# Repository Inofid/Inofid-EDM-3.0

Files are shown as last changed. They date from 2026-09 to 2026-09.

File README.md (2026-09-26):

# ⚡ EDM-3.0 Компактная и бюджетная версия настольного электроэрозионного станка



[]()

> ### 🚧 Статус разработки (Work in Progress)
>
> Проект находится в стадии активной разработки и тестирования. 
> * **Обратите внимание:** файлы схем (schematics), CAD-моделей и прошивки (Firmware) могут регулярно обновляться.
> * В процессе оптимизации некоторые текущие файлы или проектные решения могут стать неактуальными и быть полностью заменены. Рекомендуется следить за обновлениями.

<table>
  <tr>
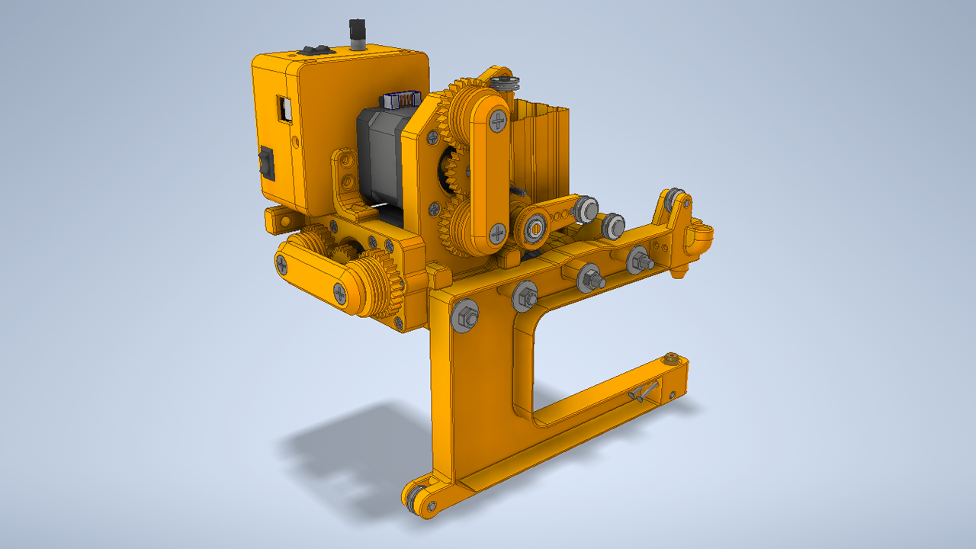
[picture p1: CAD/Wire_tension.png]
Система натяжения проволоки
    <td></td>
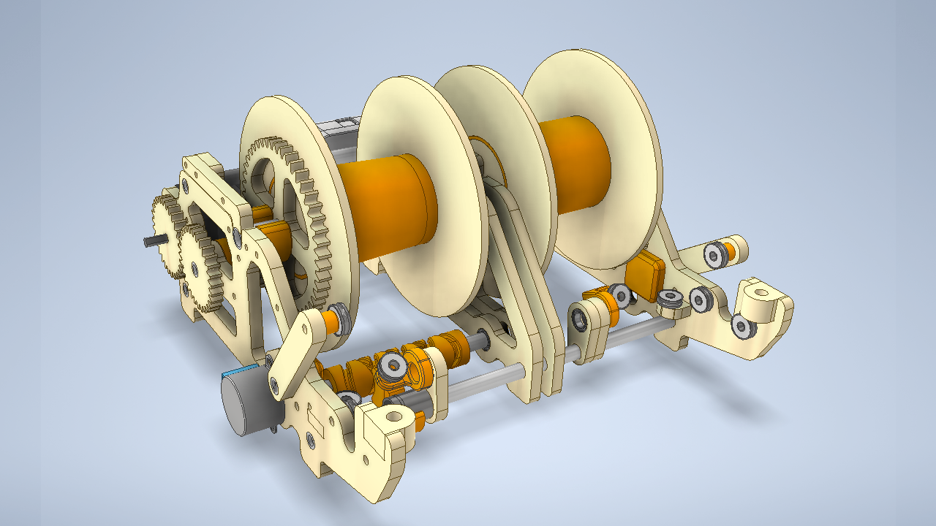
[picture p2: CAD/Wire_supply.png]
Система подачи проволоки
    <td></td>
  </tr>  
</table>

## ⚙ Архитектура и состав проекта (Project Architecture)

Система разработана для быстрой интеграции в простой и доступный ЧПУ станок **CNC3018**. (Изготовление рамы станка не входит в проект)

Для модернизации станка к его рабочему столу крепится ёмкость с водой, а стандартный шпиндель заменяется на модуль натяжения проволоки. На модуле предусмотрен квадратный посадочный выступ 40×40 мм — он вставляется в штатное гнездо бесщеточного шпинделя диаметром 52 мм, вместо самого шпинделя.

### Проект состоит из трех основных независимых систем:

### 1. Система натяжения проволоки
Устанавливается на ось Z станка вместо стандартного шпинделя. Обеспечивает стабильное натяжение проволоки в зоне реза. Проволока поступает в этот модуль из (Системы 2)
* [**3D-модель**](CAD/Wire-tension)
* [**Электрическая схема**](Hardware/Wire_tension)
* [**Прошивка**](Firmware/Wire_Tension)

### 2. Система подачи и отвода проволоки
Располагается рядом со станком. Обеспечивает непрерывную размотку свежей проволоки и смотку отработанной. Проволока поступает в модуль натяжения (Система 1) через гибкие тефлоновые трубки.
* [**3D-модель**](CAD/Wire-supply)
* [**Электрическая схема**](Hardware/Wire_supply)
* [**Прошивка**](Firmware/Wire_supply)

### 3. Генератор импульсов для электроэрозии
Главный электронный блок, который формирует электрические разряды для эрозии металла.
* [**Электрическая схема**](Hardware/Pulse_Generator)
* [**Прошивка**](Firmware/EDM_NEW)

---

## ⚙️ Требования к электронике станка (Electronics Requirements)

Стандартные платы управления CNC3018 обычно оснащены встроенными драйверами шаговых двигателей **A4988**. Однако они **не подходят** для этого проекта.

### Драйверы шаговых двигателей (Stepper Drivers)

Для работы станка необходимо выставлять **микрошаг 1/128 или 1/256**. Стандартные A4988 этого не позволяют.

**Рекомендуемые драйверы:**

- **LV8729** — использовались автором проекта. Микрошаг 1/128 выставляется с помощью перемычек (jumpers).
- **TMC2209** — также подходят, но для микрошага выше 1/64 требуется другой интерфейс подключения (UART), что может быть затруднительно.

### Настройка прошивки (Firmware Settings)

После установки драйверов необходимо изменить следующие параметры в прошивке станка (GRBL):

| Параметр | Значение | Описание |
| :--- | :--- | :--- |
| `$100` / `$101` / `$102` | 6400 | Количество шагов на мм (steps/mm) для осей X/Y/Z |
| `$120` / `$121` | 3000 | Ускорение (acceleration), мм/с² |
| `$110` / `$111` | 100 | Максимальная скорость (max rate), мм/мин |

> - ⚠️ **Количество шагов на мм** зависит от конфигурации конкретного станка. Значение **6400** указано для микрошага 1/128. Пользователь должен перепроверить его самостоятельно.
> - **Ускорение 3000 мм/с²** может показаться высоким, но станок двигается очень медленно, поэтому проблем не возникнет. Такое ускорение необходимо для корректной работы системы поддержания искрового зазора.
> - **Максимальная скорость 100 мм/мин**. Быстрые перемещения с большим микрошагом могут привести к пропуску шагов или зависанию станка, поэтому максимальная скорость ограничена.
>   - Габариты станка небольшие, рабочая область ещё меньше, а холостых перемещений практически не будет: в большинстве случаев стартовое положение выставляется вручную.
>   - Рабочая скорость обычно ещё ниже — до **15 мм/мин**.

---

## 🔌 Требования к электропитанию (Power Requirements)
> [!WARNING]
> **ВЫСОКОЕ НАПРЯЖЕНИЕ!** Система питается от **сети 220 В**. А для работы генератора импульсов используется напряжение **80 В**, которое также представляет опасность. И всё это в непосредственной близости от воды.
> * Будьте предельно осторожны при сборке, отладке и эксплуатации устройства.
> * Автор проекта не несёт ответственности за любой ущерб здоровью или имуществу, полученный в ходе повторения данной конструкции. Все действия вы производите на свой собственный страх и риск.

##

### Для работы всей системы вам понадобятся следующие компоненты:
* **Блок питания 24 В (400 Вт)** — основной источник энергии.
* **Блок питания 12 В (2 А)** — 2 шт. (для раздельного питания логики и периферии).
* **Повышающий DC-DC модуль** — мощный преобразователь, который поднимает напряжение с 24 В до 80 В.

Полная карта межблочных соединений и полярности подключения представлена на схеме ниже:

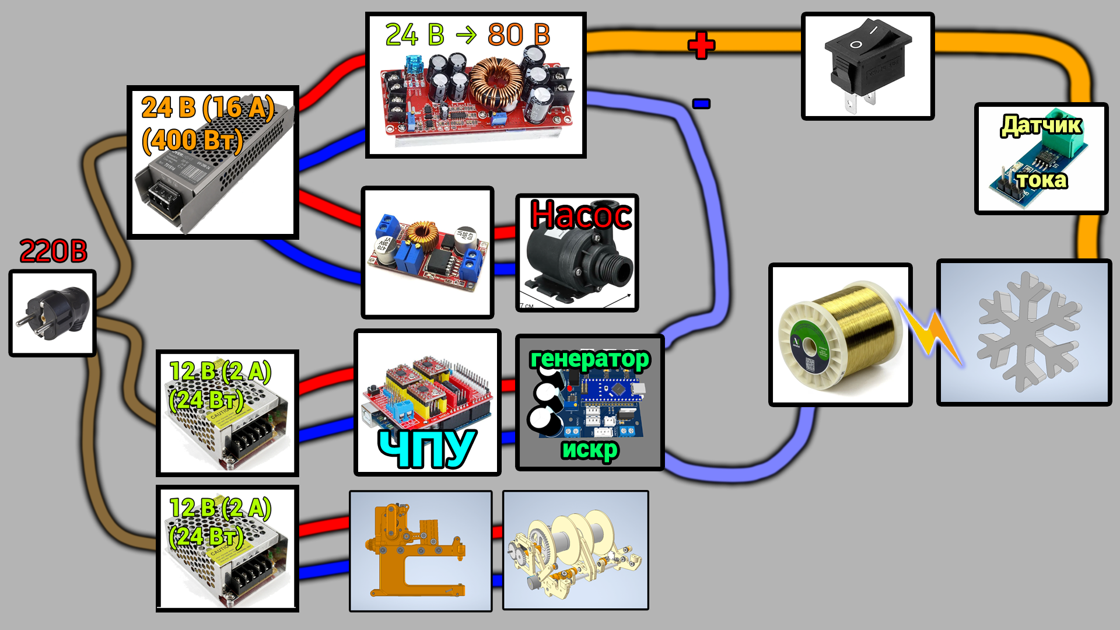
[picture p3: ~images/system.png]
Схема подключения системы


---

## 💧 Система фильтрации и подачи воды (Fluid & Filtration System)

Для эффективного удаления продуктов эрозии (шлама) из зоны реза необходима постоянная циркуляция чистой воды. Система состоит из двух узлов:

* **Магистральный фильтр стандарта SL10 (или большего размера BB10/20)** — используется совместно с многоразовым промываемым картриджем тонкой очистки на **10 мкм**.
* **Центробежный водяной насос** — требуется насос достаточной мощности. Рекомендуется использовать именно **центробежный** насос, так как он выдаёт плавный поток воды без пульсаций. Поршневые или мембранные насосы создают вибрации, которые негативно влияют на стабильность искрового промежутка и точность реза.

---

## 📺 Видео на тему (YouTube):
<table>
  <tr>
    <td align="center"><b>Бюджетный настольный EDM. Часть 1</b></td>
    <td align="center"><b>Бюджетный настольный EDM. Часть 2</b></td>
    <td align="center"><b>Бюджетный настольный EDM. Часть 3</b></td>
  </tr>
  <tr>
    <td>
      <a href="https://youtu.be/et2IkxifwoQ" target="_blank">
        Watch Video 1
      </a>
    </td>
    <td>
      <a href="https://youtu.be/vZhCjU2zuyg" target="_blank">
        Watch Video 2
      </a>
    </td>
    <td>
      <a href="https://youtu.be/VOJPKpydAsk" target="_blank">
        Watch Video 3
      </a>
    </td>
  </tr>
</table>

---

## 📂 Структура репозитория

* [`CAD/`](/CAD) — Исходные файлы (CAD) 3D-моделей для работы в программе Autodesk Inventor.
* [`3D_Models/`](/3D_ModelsD) — STL и STEP файлы для 3D-печати и редактирования в других CAD-программах
* [`Hardware/`](/Hardware) — Исходные файлы электрических схем и плат в EasyEDA
* [`Firmware/`](/Firmware) — Исходный код прошивок (Arduino Code) для микроконтроллеров.
* [`LICENSE`](LICENSE) / [`LICENSE-HARDWARE.md`](LICENSE-HARDWARE.md) — Юридические документы, регламентирующие использование материалов.

---

## ⚖️ Лицензирование (Licensing)

Проект использует двойную схему лицензирования:

* **Программное обеспечение (ПО):** Исходный код прошивки распространяется под лицензией **[MIT License](LICENSE)**.
* **Аппаратное обеспечение (Hardware, CAD):** Все схемы, чертежи, платы и 3D-модели распространяются под лицензией **[Creative Commons Attribution 4.0 International (CC BY 4.0)](LICENSE-HARDWARE.md)**. Вы можете свободно использовать и модифицировать их при условии указания авторства.

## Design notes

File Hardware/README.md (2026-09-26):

# Hardware 🔌🛠

В данном разделе представлены электрические схемы и печатные платы для аппаратных модулей электроэрозионного станка **Inofid-EDM-3.0**.

Все проекты выполнены в среде **EasyEDA**. Внутри каждой директории находятся файлы в формате `.json`, которые можно легко импортировать в EasyEDA (как Standard, так и Pro версии) для просмотра, редактирования или экспорта в Gerber-файлы для заказа плат.

---

## 📁 Структура раздела

Каждый модуль спроектирован на базе микроконтроллера **Arduino Nano** и выполняет свою изолированную задачу в системе станка:

* **Pulse_Generator** — схема генератора высокочастотных импульсов (искрогенератора). Отвечает за управление силовыми мосфетами и обработку обратной связи от датчика тока (компаратора).
  * 💾 **Прошивка:** [EDM_NEW](https://github.com/Inofid/Inofid-EDM-3.0/tree/main/Firmware/EDM_NEW)
* **Wire_supply** — схема системы автоматической подачи свежей и отвода отработанной проволоки. Управляет шаговыми двигателями катушек на основе положения рычагов.
  * 💾 **Прошивка:** [Wire_supply](https://github.com/Inofid/Inofid-EDM-3.0/tree/main/Firmware/Wire_supply)
* **Wire_tension** — схема системы контроля натяжения проволоки. Динамически подстраивает скорость шагового двигателя через PID-алгоритм для поддержания стабильного натяжения.
  * 💾 **Прошивка:** [Wire_Tension](https://github.com/Inofid/Inofid-EDM-3.0/tree/main/Firmware/Wire_Tension)

---

## 🖼 Галерея проектов

| Название проекта | Pulse_Generator | Wire_supply | Wire_tension |
| :--- | :---: | :---: | :---: |
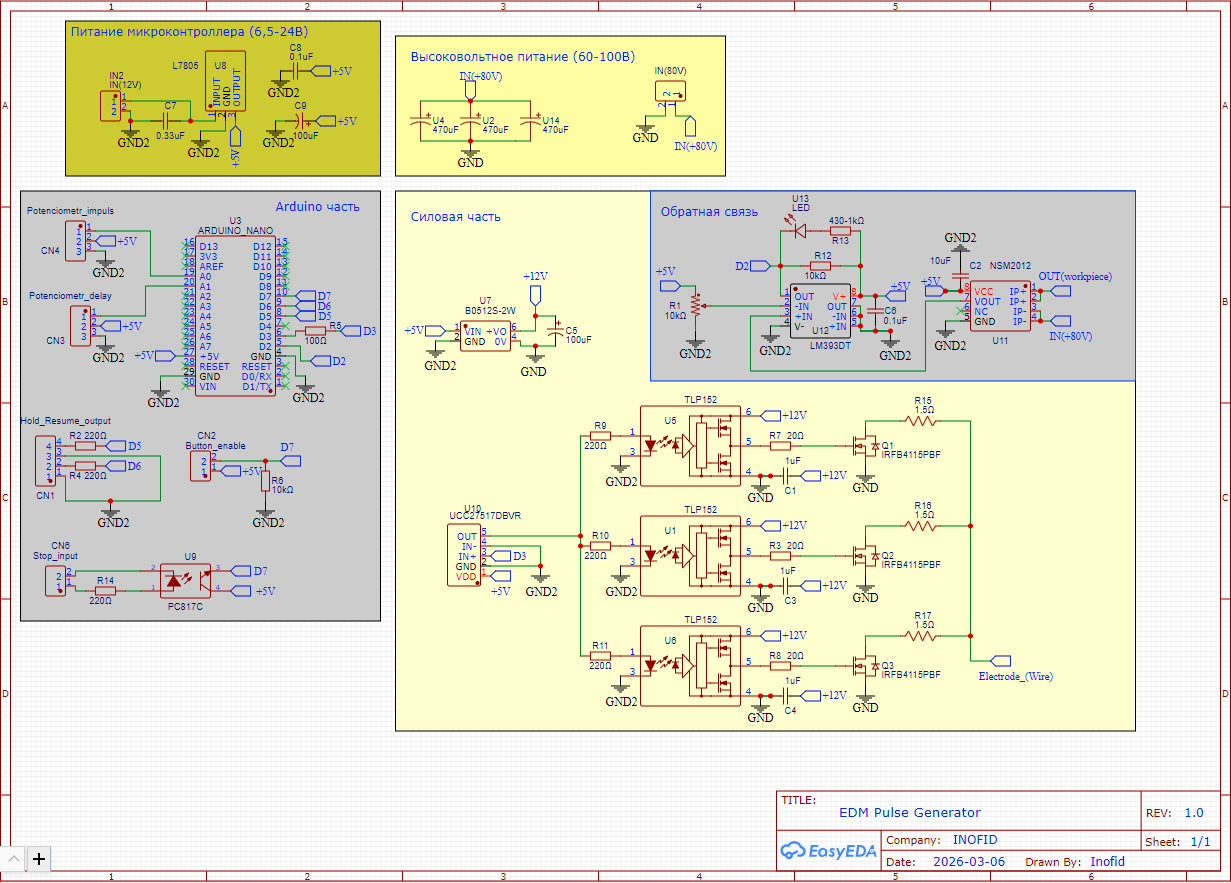
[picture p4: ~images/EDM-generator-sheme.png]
Схема Pulse_Generator
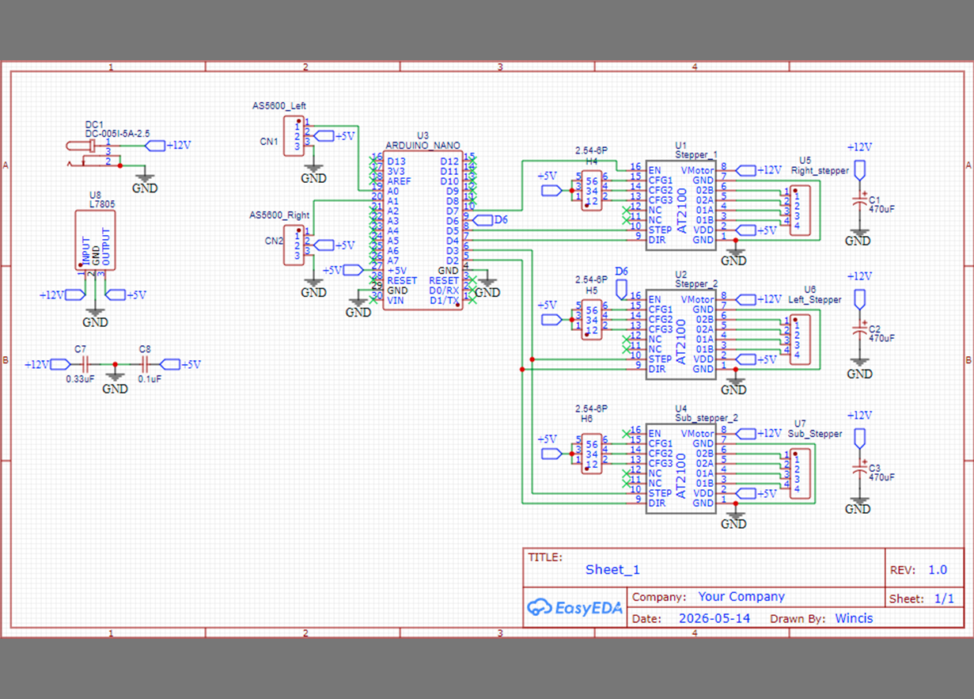
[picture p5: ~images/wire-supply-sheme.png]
Схема Wire_supply
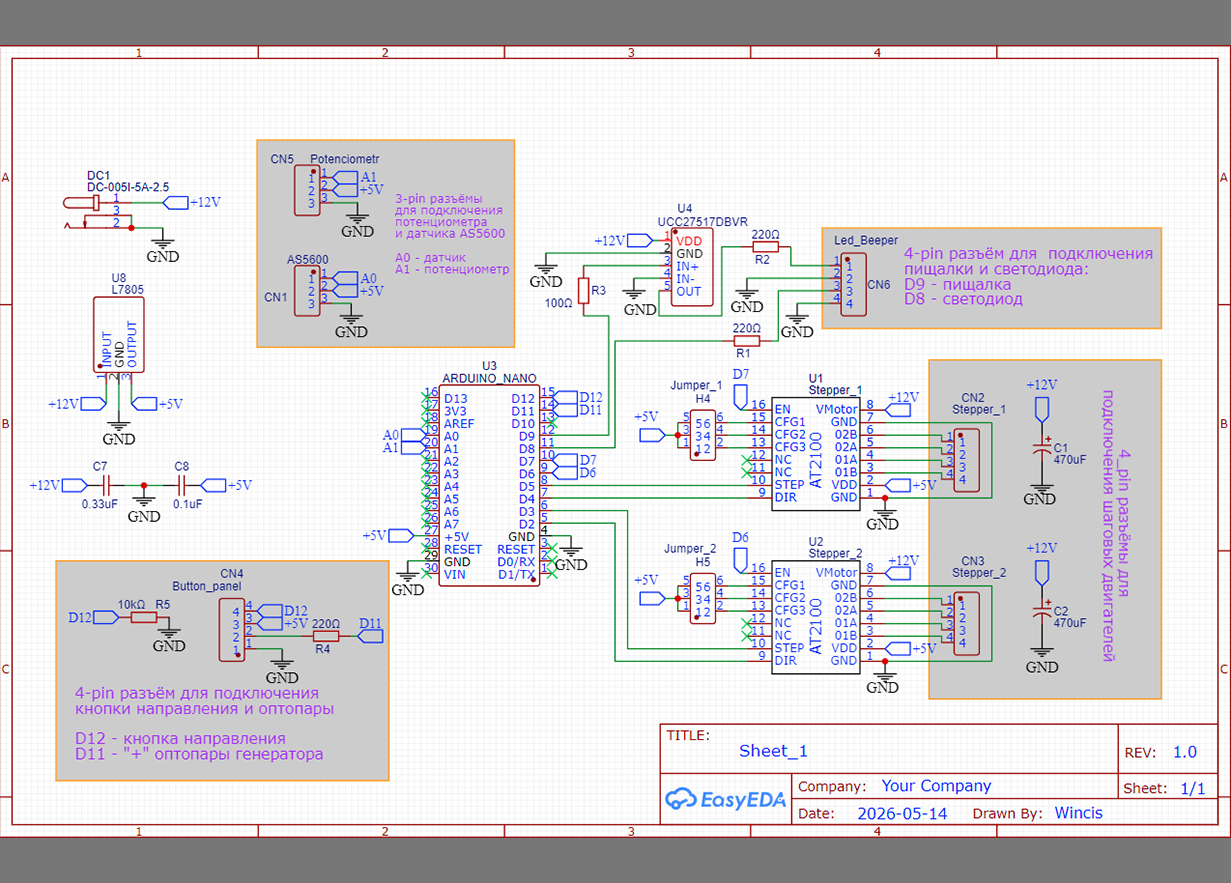
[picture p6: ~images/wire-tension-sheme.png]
Схема Wire_tension
| **Электрическая схема** |  |  |  |
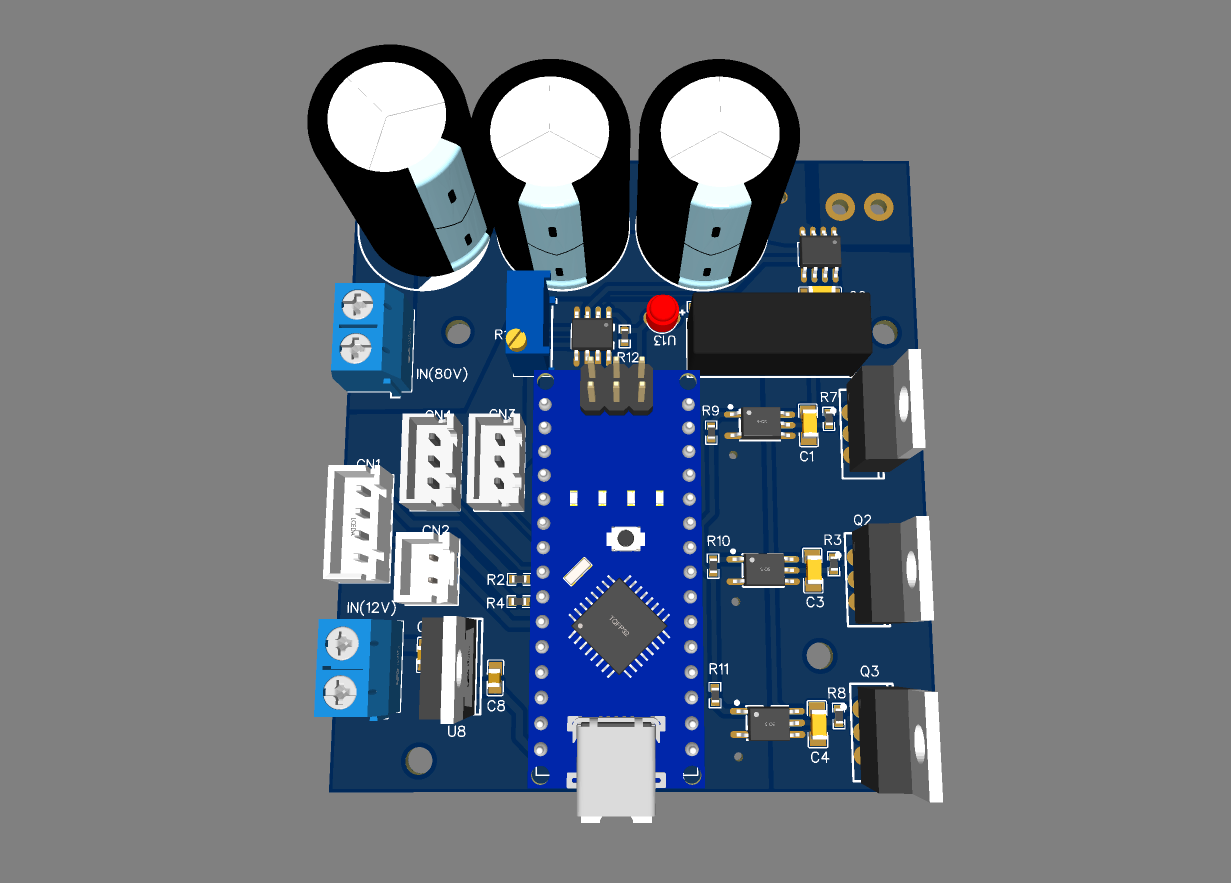
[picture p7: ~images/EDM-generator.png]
Плата Pulse_Generator
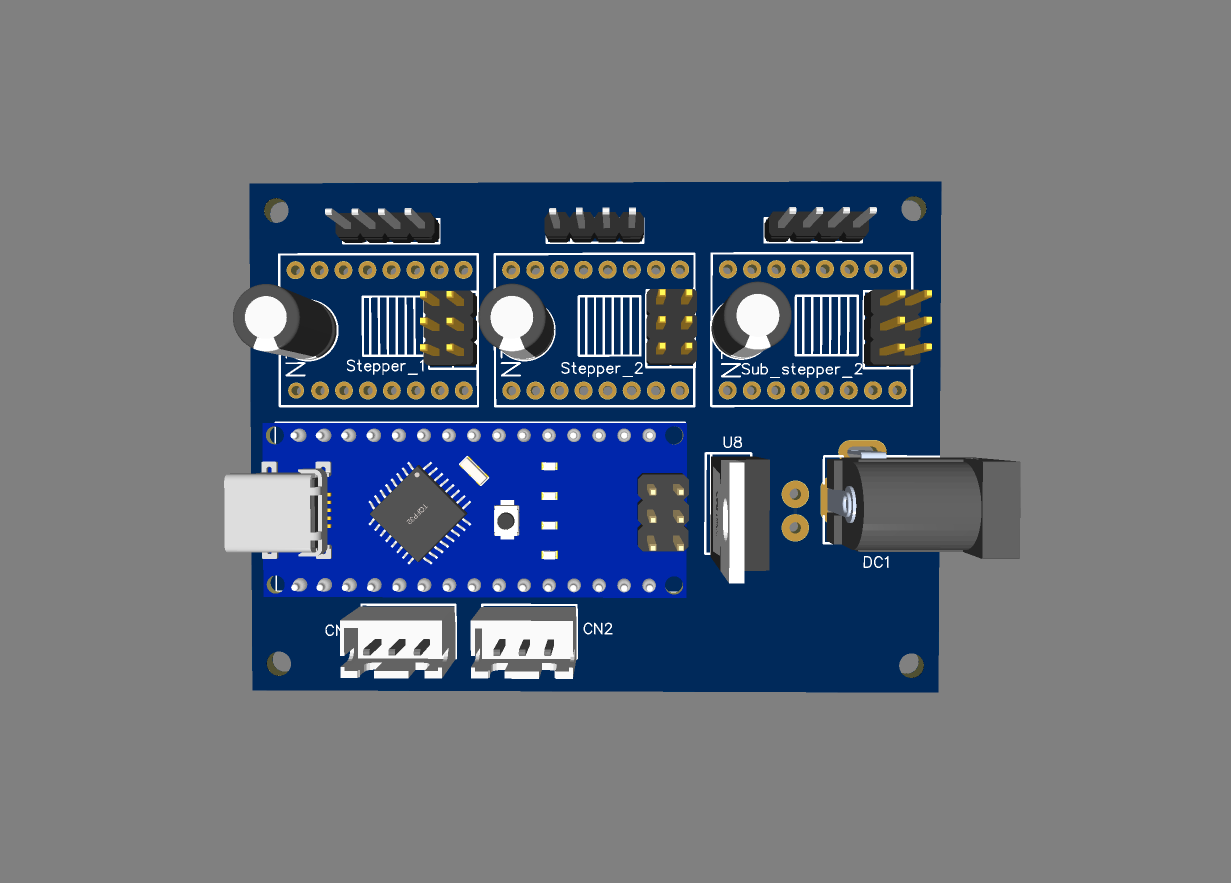
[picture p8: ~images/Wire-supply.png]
Плата Wire_supply
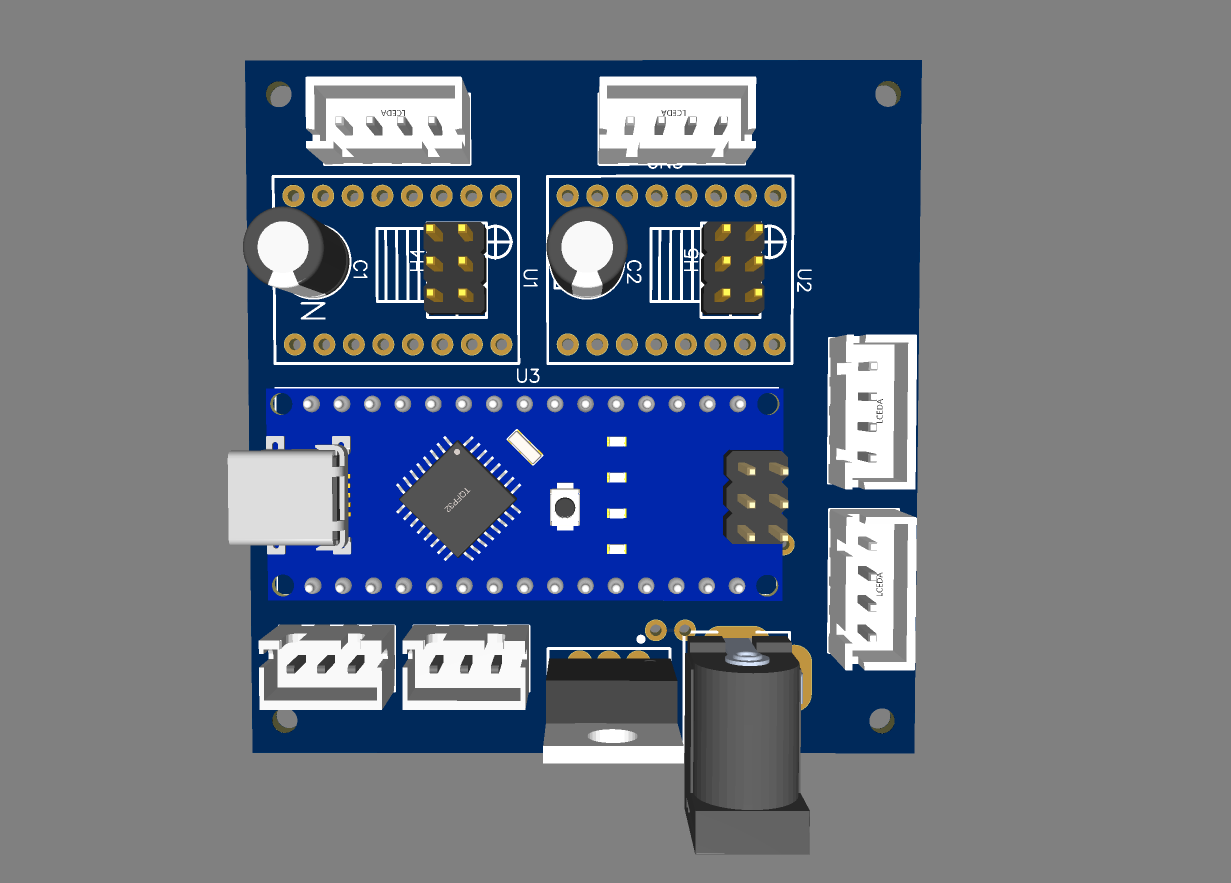
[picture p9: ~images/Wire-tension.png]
Плата Wire_tension
| **Внешний вид платы** |  |  |  |

---

## 🚀 Как открыть файлы в EasyEDA

1. Откройте онлайн-редактор [EasyEDA](https://easyeda.com/editor) или запустите десктопное приложение.
2. В верхнем левом меню выберите: **Файл (File)** ➡️ **Открыть (Open)** ➡️ **EasyEDA...**
3. Загрузите соответствующий `.json` файл из папки интересующего вас модуля.

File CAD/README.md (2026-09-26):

# 3D-модели Autodesk Inventor

В этой папке содержатся исходные файлы 3D-моделей, сборочных узлов и отдельных деталей, созданных в **Autodesk Inventor**.

### Предварительный просмотр 3D-моделей
<table>
  <tr>
    <td align="center"><b>Система натяжения проволоки</b></td>
    <td align="center"><b>Система подачи проволоки</b></td>
  </tr>
  <tr>
    <td>Система натяжения проволоки</td>
    <td>Система подачи проволоки</td>
  </tr>
</table>

### Расположение файлов:
*  В папке "Wire-tension" — главный файл сборки **"Модуль.iam"**
*  В папке "Wire-supply" — главный файл сборки **"Система подачи и забора проволоки.iam"**

### Информация об изготовлении деталей:
* **Проект в папке "Wire-tension"** — полностью рассчитан на печать всех деталей на 3D-принтере. Рамка выполнена в виде формы для заливки бетоном/полимербетоном.
* **Проект в папке "Wire-supply"** — содержит детали двух типов:
  * 🟠 **Оранжевые детали** — печатаются на 3D-принтере.
  * 🟡 **Бежевые детали** — вырезаются на лазерном станке из фанеры толщиной 6 мм. Фанерные детали соединены алюминиевыми трубками 8 мм.

### Типы файлов в этой папке:
* `.iam` — файлы сборок 
* `.ipt` — файлы отдельных деталей

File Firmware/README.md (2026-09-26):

# Прошивка и исходный код

В этой папке находится исходный код (скетчи Arduino) для подсистем управления электроэрозионного (EDM) станка. Прошивка разделена на модули для трех отдельных микроконтроллеров.

## Обзор подсистем

*   📂 **[EDM_NEW](./EDM_NEW)** — Прошивка генератора импульсов. Отвечает за управление высокочастотными электрическими разрядами и контроль искрового промежутка.
*   📂 **[Wire_Tension](./Wire_Tension)** — Система управления натяжением проволоки. Управляет контуром обратной связи для поддержания оптимального натяжения проволоки во время работы.
*   📂 **[Wire_supply](./Wire_supply)** — Система подачи и приемки проволоки. Контролирует непрерывную подачу свежей, и отвод отработанной проволоки.

---

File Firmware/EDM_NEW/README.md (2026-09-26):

# Генератор импульсов (искрогенератор) (Arduino Nano)

Данный скетч предназначен для управления мосфетами, генерирующими высокочастотные импульсы, и автоматического регулирования подачи станка на основе обратной связи от датчика тока (компаратора).

> [!WARNING]
> ⚠️ **ВНИМАНИЕ! ВЫСОКОЕ НАПРЯЖЕНИЕ!** Для работы генератора импульсов используется опасное для жизни напряжение **80 В**. 
> * Будьте предельно осторожны при сборке, отладке и эксплуатации устройства. Особенно с учётом наличия рядом ёмкости с водой.
> * Автор проекта не несёт ответственности за любой ущерб здоровью или имуществу, полученный в ходе повторения данной конструкции. Все действия вы производите на свой собственный страх и риск.

## 📌 Распиновка и схема подключений

### 1. Входы (Inputs)
*   **A0** — Потенциометр длительности импульса (регулировка диапазона **2–25 мкс**).
*   **A1** — Потенциометр паузы между импульсами (регулировка частоты **1–20 кГц**, диапазон паузы **40–1000 мкс**).
*   **D7** — Переключатель режимов (Настройка / Работа).
    >⚠️ Пин должен быть обязательно **подтянут к GND через резистор 10 кОм**. При замыкании переключателя, на D7 подается **+5V** с платы Arduino.
*   **D4** — Вход сигнала с компаратора датчика тока.
    >⚠️ Опрос этого пина в коде происходит строго **в конце импульса**, непосредственно перед закрытием мосфета. Это критично для обратной связи, так как ток в цепи может отсутствовать в начале импульса, но может появиться ближе к его завершению. Это позволяет более корректно оценивать был ли импульс холостым или полезным.

### 2. Выходы (Outputs)
*   **D3** — Выход сигнала управления драйвером силовых MOSFET-ключей.
*   **D5** — Выход на оптопару **RESUME** (Продолжение движения).
*   **D6** — Выход на оптопару **PAUSE / HOLD** (Станок на паузу).

---

## 🔌 Подключение оптопар и интеграция со станком

Светодиодная (входная) часть обеих оптопар подключается к Arduino по классической схеме:
*   **Анод (+)** оптопары — к соответствующему пину Arduino (**D5** или **D6**) через токоограничивающий **резистор 220 Ом**.
*   **Катод (-)** оптопары — напрямую на **GND** платы Arduino.

Так как оптопары (PC 817) не являются частью родной платы управления станком, а подключаются отдельно, их выходная (транзисторная) часть подключается к пинам `Hold` и `Resume` контроллера станка следующим образом:
*   **Эмиттер** транзистора оптопары — соединяется с **GND** платы управления станком.
*   **Коллектор** транзистора оптопары — подключается к сигнальному входу пина **Hold** (для оптопары с D6) или пина **Resume** (для оптопары с D5).

---

## ⚙️ Логика работы

1.  **Режим настройки (На D7 подано +5V):**
    *   Генерация импульсов полностью останавливается (мосфет закрыт).
    *   Включается оптопара PAUSE на пине D6 (станок замораживает движение).
    *   В реальном времени считываются показания с потенциометров A0 и A1 для калибровки таймингов.
2.  **Режим работы (На D7 подан GND через 10 кОм):**
    *   Запускается циклическая генерация импульсов заданной длительности на пине D3.
    *   В конце каждого импульса опрашивается состояние пина D4. Если зафиксирован ток, инкрементируется внутренний счетчик `q`, если тока нет — декрементируется.
    *   **Автоматика:** При избытке полезных импульсов (`q >= 950`) активируется пин D6 (Hold), приостанавливая подачу станка. При нехватке импульсов (`q <= 850`) активируется пин D5 (Resume), возобновляя движение.
> ###  ⚠️ **Примечание:** 
> Опрос потенциометров происходит только в режиме настройки (когда на D7 подано 5В). Поэтому не получится изменять частоту и длительность импульсов в режиме реального времени во время работы станка. Такая реализация нужна > из-за медлительности микроконтроллера Atmega328. Опрос потенциометров занимает слишком много времени, что нарушает стабильность генерации импульсов.
***

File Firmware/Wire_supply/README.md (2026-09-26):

# Wire_supply 🧵🎛️

Прошивка для **Arduino Nano**, управляющая системой автоматической подачи свежей и отвода отработанной проволоки для **электроэрозионного станка (EDM)**.

---

## 📋 Описание системы

Система состоит из двух идентичных модулей:
* **Модуль подачи** свежей проволоки
* **Модуль отвода** отработанной проволоки

Каждый модуль оснащен катушкой и подпружиненным рычагом контроля натяжения. Шаговые двигатели вращают катушки, а скорость их вращения динамически рассчитывается с помощью **PID-регулятора** (`GyverPID`) на основе угла наклона рычагов. Это позволяет непрерывно поддерживать оптимальное натяжение проволоки.

### 🛑 Логика «мёртвой» зоны и обрыва:
* **Автоостановка**: При запуске станка, а также в случае обрыва проволоки, пружины уводят рычаги в крайнее положение. Если показания датчика выходят за рабочий диапазон (становятся **меньше 50** или **больше 600**), прошивка расценивает это как «мёртвую» зону и останавливает шаговые двигатели.
* **Быстрый старт**: Чтобы запустить систему, достаточно вручную натянуть проволоку или отклонить рычаг, выведя датчик из мёртвой зоны. Двигатели запустятся автоматически.

---

## 🔌 Подключение компонентов

| Компонент | Пин Arduino Nano | Описание |
| :--- | :---: | :--- |
| **Шаговый двигатель 1 (Драйвер TMC2209)** | `D3` (STEP), `D2` (DIR) | Вращение катушки 1 [4] |
| **Шаговый двигатель 2 (Драйвер TMC2209)** | `D5` (STEP), `D4` (DIR) | Вращение катушки 2 [4] |
| **Датчик AS5600 №1 (в аналоговом режиме)** | `A0` (OUT) | Положение рычага 1 [4] |
| **Датчик AS5600 №2 (в аналоговом режиме)** | `A1` (OUT) | Положение рычага 2 [4] |

---

## 🛠️ Настройка и калибровка датчиков AS5600

В проекте используются магнитные энкодеры **AS5600**, переведённые в аналоговый режим работы.

### 1. Перевод в аналоговый режим
Чтобы датчик выдавал непрерывное аналоговое напряжение вместо I2C/PWM сигналов, на плате модуля необходимо **отпаять резистор R4**. 
После чего датчик будет работать в аналоговом режиме и на пине **"`OUT`"** будет выдавать напряжение от 0 В до 5 В, в зависимости от положения рычага.

Размещение резистора указано на изображении ниже:

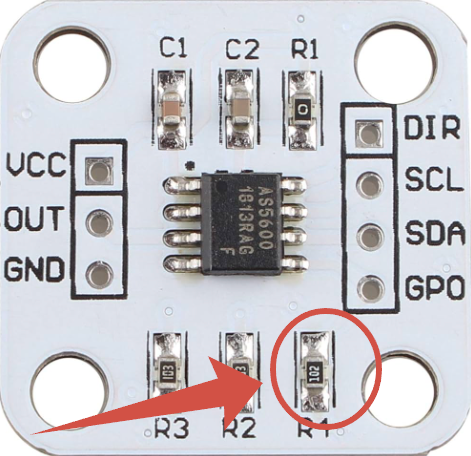
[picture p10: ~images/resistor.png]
Расположение резистора R4


### 2. Зеркальное изменение направления (DIR)
Так как модули на станке расположены зеркально друг относительно друга, направления движения рычагов противоположны. Для корректной работы PID-алгоритма нужно настроить пин `DIR` на самих датчиках:
* **На первом датчике**: Замкните пин `DIR` на **GND**.
* **На втором датчике**: Замкните пин `DIR` на **VCC**.

> **Проверка**: При наклоне обоих рычагов из начального положения в рабочее, значения на аналоговых входах должны **увеличиваться**.

### 3. Калибровка положения магнитов
Перед запуском необходимо физически отъюстировать магниты на осях рычагов. В **свободном (начальном)** положении подпружиненного рычага датчик должен выдавать значения `analogRead()` в диапазоне **от 10 до 15**.

Залейте в Arduino этот простой калибровочный скетч и вращайте магнит, пока не добьетесь значений в мониторе порта (от 10 до 15):

```cpp
void setup() {
  Serial.begin(9600);
}

void loop() {
  // Считываем значения с пинов A0 и A1
  int sensor1 = analogRead(A0);
  int sensor2 = analogRead(A1);

  // Выводим данные в монитор порта
  Serial.print("Рычаг 1 (A0): ");
  Serial.print(sensor1);
  Serial.print("\t | \tРычаг 2 (A1): ");
  Serial.println(sensor2);

  delay(150); // Задержка для удобства чтения
}
```

---

## 📚 Зависимости
Для сборки основного проекта `Wire_supply` необходимы библиотеки:
* [TimerOne](https://github.com) — для генерации стабильных прерываний таймера.
* [GyverPID](https://github.com) — для работы PID-регуляторов.

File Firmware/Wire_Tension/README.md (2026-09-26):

# Wire Tension Controller (Arduino Nano)

Данный проект представляет собой систему автоматического контроля натяжения проволоки на базе микроконтроллера **Arduino Nano**. Устройство управляет двумя шаговыми двигателями: скорость первого динамически подстраивается через PID-регулятор для поддержания натяжения, а скорость второго задается вручную пользователем.

---

## ⚙️ Основные функции
* **Автоматическое поддержание натяжения:** Отслеживание положения рычага с помощью магнитного энкодера AS5600 и корректировка скорости ШД через PID-алгоритм.
* **Ручное управление вторым ШД:** Регулировка скорости потенциометром и смена направления вращения с помощью кнопки.
* **Безопасность и мониторинг:** 
  * Определение обрыва проволоки или выхода рычага за рабочие пределы с автоматической остановкой моторов и звуковым оповещением.
  * Контроль проскальзывания проволоки при сильном расхождении скоростей двигателей.
---

## 🔌 Схема подключения (Пинкаут)

### 1. Шаговые двигатели & Драйверы (TMC2209)

| Назначение | Пин Arduino | Описание |
|---|---|---|
| **STEP 1** | `D3` | Пин Step драйвера 1-го ШД |
| **DIR 1** | `D2` | Пин Dir драйвера 1-го ШД  |
| **ENABLE 1** | `D6` | Пин Enable драйвера 1-го ШД |
| **STEP 2** | `D5` | Пин Step драйвера 2-го ШД |
| **DIR 2** | `D4` | Пин Dir драйвера 2-го ШД  |
| **ENABLE 2** | `D7` | Пин Enable драйвера 2-го ШД  |

### 2. Датчики и Органы управления

| Компонент | Пин Arduino | Описание |
|---|---|---|
| **AS5600 (Out)** | `A0` | Аналоговый выход датчика положения рычага  |
| **Потенциометр** | `A1` | Регулятор скорости 2-го ШД (шаги/сек)  |
| **Кнопка направления** | `D12` | Переключатель направления 2-го ШД. При нажатии — подает `5V`, при отпускании — подтянут к `GND` через резистор **10 кОм**  |

### 3. Индикация и Оповещение

| Компонент | Пин Arduino | Описание |
|---|---|---|
| **Сигнальный LED** | `D8` | Светодиод аварии/проскальзывания (подключать через резистор **220 Ом**)  |
| **Пищалка (Buzzer)** | `D9` | Выход на специализированный драйвер **UCC27517DBVR** (для обеспечения достаточного тока и громкого звука пищалки. Напрямую от пина Arduino питать пищалку нельзя). |

---

## 🛠 Настройка датчика AS5600

### 1. Перевод модуля AS5600 в аналоговый режим
По умолчанию большинство плат датчика AS5600 настроены на работу по шине I2C или выдают ШИМ (PWM). Чтобы перевести датчик в **режим вывода аналогового напряжения (Analog Out)** на пине **"`OUT`"**:
* На стандартных китайских платах AS5600 необходимо **отпаять резистор R4**, подтягивающий пин выбора режима. Это переводит выходной каскад микросхемы в режим `Analog Ratiometric`, выдающий от 0 до 5V пропорционально углу поворота.

Resistor AS5600

### 2. Калибровка магнита и рычага
Для корректной работы PID-регулятора в начальном положении рычага значение `analogRead(A0)` должно находиться строго в диапазоне **от 0 до 15**. 

Используйте этот короткий тестовый скетч для точной юстировки магнита:

```cpp
void setup() {
  Serial.begin(9600);
  pinMode(A0, INPUT);
}

void loop() {
  int rawValue = analogRead(A0);
  Serial.print("Положение магнита (Analog A0): ");
  Serial.println(rawValue);
  delay(200); // Задержка для читаемости в мониторе порта
}
```

**Инструкция по настройке:**
1. Залейте тестовый скетч в Arduino Nano.
2. Переведите рычаг устройства в **исходное (начальное) положение**.
3. Вращайте и смещайте постоянный магнит на оси рычага относительно микросхемы AS5600, пока в Мониторе порта значения `analogRead` не стабилизируются в диапазоне **0...15**.
4. Надежно зафиксируйте магнит в этом положении.
 #### ⚠️Обратите внимание, что при наклоне рычага в рабочем направлении, значение должно увеличиваться, а не уменьшаться. Если это не так, то пин DIR на модуле AS5600 необходимо замкнуть либо на GND, либо на VCC.
---

## 🔍 Алгоритм обнаружения проскальзывания

Система безопасности непрерывно контролирует разницу скоростей между двумя двигателями во избежание проскальзывания проволоки:
1. Скорость 2-го двигателя (`spd2`) задается жестко потенциометром.
2. Скорость 1-го двигателя (`spd1`) динамически рассчитывается PID-регулятором.
3. Каждые 40 итераций основного цикла происходит сверка скоростей (проверка завязана на программный счетчик `i` из-за перегрузки таймера прерываниями, управляющими ШД).
4. Если модуль разницы скоростей превышает **200 шагов/сек** (`abs(spd2 - abs(spd1)) > 200`), устройство считает, что проволока проскальзывает, и генерирует короткий звуковой/световой сигнал.

---

## 🚀 Инструкция по эксплуатации

### Старт работы и сброс аварии
1. При включении устройства рычаг находится в начальном положении (`analogRead(A0) < 15`).
2. Система сразу переходит в режим аварии: моторы отключены, а пищалка издает двухтональный протяженный сигнал тревоги.
3. **Для запуска работы:** необходимо **вручную наклонить рычаг** натяжителя так, чтобы датчик попал в рабочую зону (значение `analogRead(A0)` станет больше 15).
4. Как только рычаг зафиксирован в рабочей зоне, двигатели автоматически активируются, и PID-регулятор начинает удерживать заданное натяжение.

---

## 📁 Структура проекта

Проект логически разделен на модули (вкладки в Arduino IDE) для удобства чтения:
* **`Wire_Tension.ino`** — главный файл. Инициализирует периферию, содержит основной цикл `loop()` с логикой аварии, расчетом PID и маппингом потенциометра.
* **`alarm.ino`** — функции оповещения: `alarm()` для обработки обрыва/старта и `alarm_slippage()` для индикации проскальзывания.
* **`pid.ino`** — инициализация и конфигурирование базовых параметров PID-регулятора (`Kp`, `Ki`, `Kd`, направление регулирования и лимиты скоростей).
* **`timers.ino`** — обработчик прерывания таймера `timerISR()` для пошаговой генерации импульсов ШД, а также функции установки скоростей `setSpeed1()` и `setSpeed2()` с прямым управлением регистрами портов (`PORTD`) для максимального быстродействия.

## 📚 Зависимости
Для компиляции скетча требуются библиотеки:
* **TimerOne** (генерация точных интервалов шагов в прерывании)
* **GyverPID** (библиотека PID-регулятора от AlexGyver)

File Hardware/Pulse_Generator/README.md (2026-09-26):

# ⚡ Генератор импульсов для электроэрозионного станка (Pulse Generator)

<table>
  <tr>
    <td align="center"><b>Схема генератора импульсов</b></td>
    <td align="center"><b>Готовая плата генератора</b></td>
  </tr>
  <tr>
    <td>Принципиальная схема генератора импульсов</td>
    <td>Фото готовой печатной платы генератора</td>
  </tr>
</table>

> [!WARNING]
> ⚠️ **ВНИМАНИЕ! ВЫСОКОЕ НАПРЯЖЕНИЕ!** Для работы генератора импульсов используется опасное для жизни напряжение **80 В**.
> * Будьте предельно осторожны при сборке, отладке и эксплуатации устройства. Особенно с учётом наличия рядом ёмкости с водой.
> * Автор проекта не несёт ответственности за любой ущерб здоровью или имуществу, полученный в ходе повторения данной конструкции. Все действия вы производите на свой собственный страх и риск.

---

## 📖 Описание

Электронная схема генератора импульсов для электроэрозионного станка на базе **Arduino Nano**.

Устройство генерирует прямоугольные импульсы с настраиваемой длительностью и частотой, а также определяет факт возникновения искры (электрического разряда) во время импульса.

* **Логика работы** более подробно описана в папке с [прошивкой](../../Firmware/EDM_NEW)

---

## ⚙️ Состав устройства

Схема состоит из **5-ти основных блоков**:

### 1. Питание микроконтроллера (12–24 В)

- **Разъём питания** для подачи входного напряжения.
- **Стабилизатор L7805** понижает входное напряжение до **5 В**.
  - Керамический конденсатор **0,33 мкФ** на входе и **0,1 мкФ** на выходе — требование даташита.
  - Электролитический конденсатор **100 мкФ** — для дополнительной стабилизации.

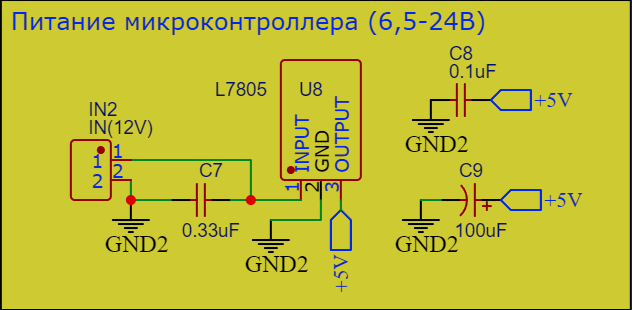
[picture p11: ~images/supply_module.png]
supply_module


### 2. Блок Arduino Nano

- **Разъём (U3)** для установки платы Arduino Nano.
- **Разъёмы** для подключения потенциометров, регулирующих длительность импульсов (CN4) и частоту (CN3).
- **Разъём (CN1)** для подключения внешних оптопар, управляющих пинами **HOLD/RESUME** на плате управления станком.
- **Разъём (CN2)** для подключения кнопки (подаёт 5 В на пин **D7**).
- **Разъём (CN6)** для управления оптопарой. Эта оптопара дублирует кнопку выше, то есть также подаёт 5 В на пин **D7**. Оптопара активируется модулем натяжения проволоки в случае обрыва проволоки, таким образом станок переходит в режим паузы.

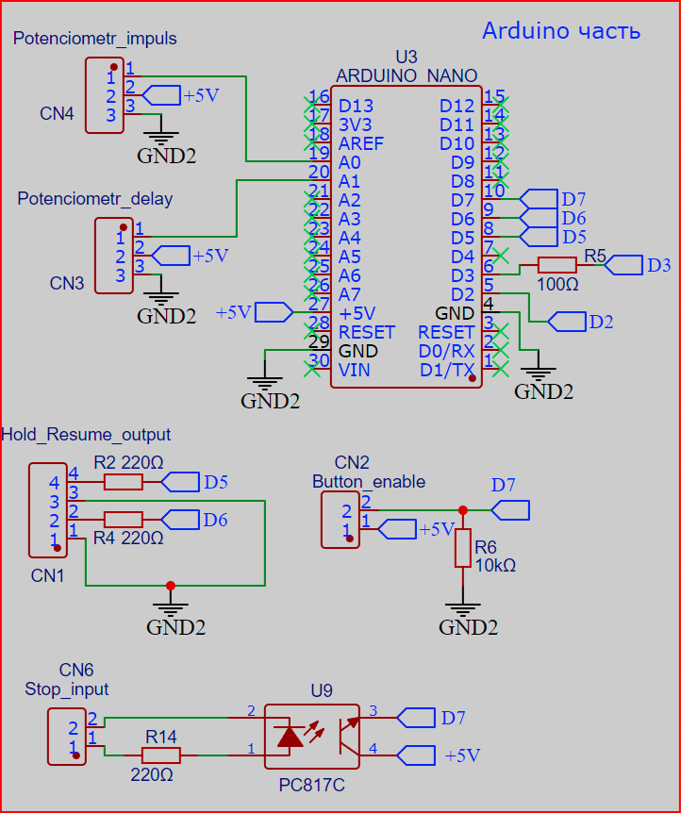
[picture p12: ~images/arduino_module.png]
arduino_module


### 3. Высоковольтное питание

- **Разъём** для подключения напряжения от **60 до 100 В**.
- **Блок конденсаторов** с низким ESR (470 мкФ).

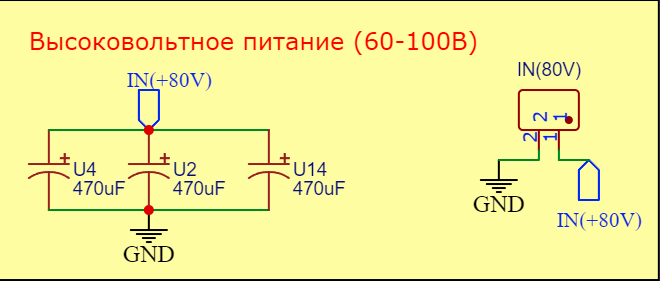
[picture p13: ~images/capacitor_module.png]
capacitor_module


### 4. Силовая часть

- **Элемент B0512S-2W** — модуль гальванической развязки повышает **5 В до 12 В**, необходимых для управления затворами мосфетов.
  - На выходе электролитический конденсатор на **100 мкФ** для стабилизации питания.
- **Сигнал** от пина **D3** Arduino поступает на драйвер **UCC27517DBVR**. Драйвер через резисторы **220 Ом** управляет тремя оптодрайверами **TLP152**. Каждый оптодрайвер через резистор **20 Ом** управляет соответствующим мосфетом **IRFB4115PBF**. Питание **12 В** для управления затворами поступает от модуля гальванической развязки **B0512S-2W**.
  - Параллельно и как можно ближе к контактам питания элементов **TLP152** стоят керамические конденсаторы на **1 мкФ**.
- **На выходе каждого мосфета** стоит нагрузочный резистор **1,5 Ом** мощностью **100 Вт** (тип **AH-100**). Он нужен для защиты мосфета в случаях короткого замыкания.
  - **Важно:** эти резисторы выносятся за пределы печатной платы и монтируются на радиаторы, так как выделяют значительное количество тепла.
- **Параллельно каждому мосфету** стоит защитный диод **1.5KE120A**. Их задача — защищать мосфеты от индукционных выбросов.
- **На выходе** резисторы соединяются вместе, и ток дальше подаётся через токосъёмники на проволоку.
- **Мосфеты** крайне желательно снабдить радиаторами. Также и резисторы желательно прикрутить к радиаторам либо организовать активное охлаждение.

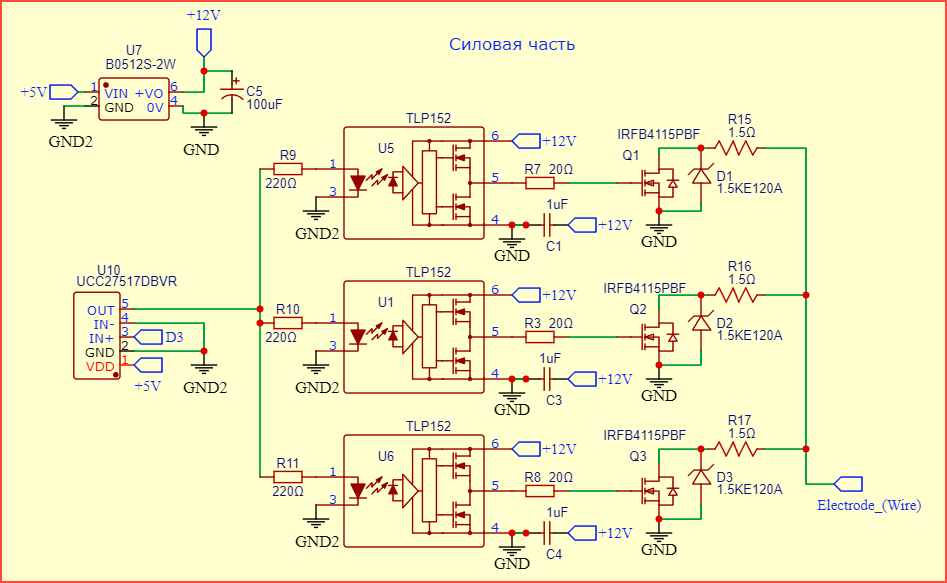
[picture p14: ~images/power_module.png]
power_module


### 5. Обратная связь

- **Плюсовая линия питания 80 В** проходит через датчик тока **NSM2012**
  > (датчик тока размещён после конденсаторов, он должен мгновенно реагировать на каждый импульс).
- **Сигнальный выход** этого датчика поступает на вход компаратора **LM393DT**.
- **Порог срабатывания** компаратора устанавливается вручную с помощью подстроечного резистора.
- **Момент срабатывания** можно увидеть благодаря светодиоду.

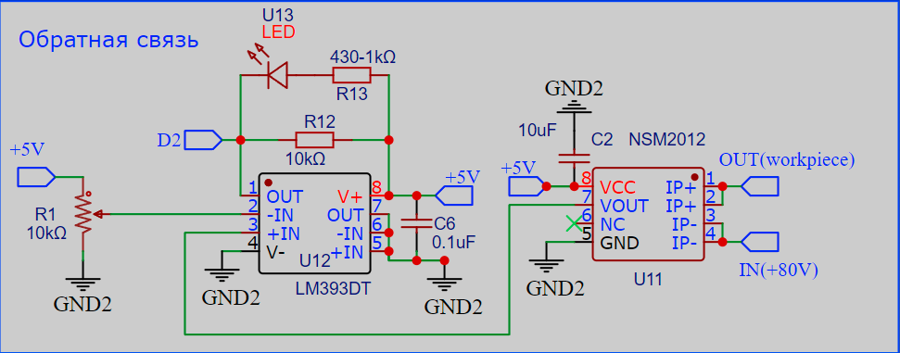
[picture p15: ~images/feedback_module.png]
feedback_module


**Настройка порога срабатывания компаратора:**

1. Выставить минимальную длительность импульсов и частоту.
2. Замкнуть проволоку и заготовку, чтобы было короткое замыкание.
3. Запустить генерацию импульсов (генератор спокойно выдержит короткое замыкание).
4. Подкрутить подстроечный резистор, пока не загорится светодиод.
5. Отвести проволоку от заготовки, чтобы разомкнуть цепь, и убедиться, что светодиод погас.
6. Желательно перепроверить несколько раз, что компаратор правильно срабатывает на замыкание/размыкание цепи.

---

## 📝 Примечания

> Потенциометр, регулирующий частоту импульсов, на самом деле регулирует длительность паузы между импульсами. Это косвенно связано с частотой, но при повороте потенциометра по часовой стрелке длительность паузы будет увеличиваться, а частота соответственно уменьшаться. Это не совсем привычно. Если это сбивает с толку, то на потенциометре можно просто поменять местами пины питания. Тогда при повороте потенциометра вправо будет увеличиваться частота импульсов (а длительность паузы соответственно уменьшаться).

> **О проводах:** Провода, идущие к заготовке и проволоке, должны быть потолще и скручены в витую пару для снижения их индуктивности и защиты окружающей электроники от электромагнитных помех.

---

## 📋 Список компонентов

| № | Компонент | Номинал / Модель | Кол-во | Примечание |
|---|---|---|:---:|---|
| 1 | Стабилизатор напряжения | L7805 | 1 | Понижает входное напряжение до 5 В |
| 2 | Плата Arduino | Arduino Nano | 1 | Микроконтроллер |
| 3 | Модуль гальванической развязки | B0512S-2W | 1 | 5 В → 12 В |
| 4 | Драйвер MOSFET | UCC27517DBVR | 1 | Управление оптодрайверами |
| 5 | Оптодрайвер | TLP152 | 3 | Управление мосфетами |
| 6 | Оптопара | PC817C | 1 | Гальваническая развязка сигнала D7 |
| 7 | MOSFET | IRFB4115PBF | 3 | Силовые ключи |
| 8 | Датчик тока | NSM2012 | 1 | Измерение тока |
| 9 | Компаратор | LM393DT | 1 | Сравнение сигнала |
| 10 | Светодиод | LED (красный) | 1 | Индикация срабатывания |
| 11 | Диод защитный | 1.5KE120A | 3 | Защита от индукционных выбросов |
| 12 | Конденсатор керамический | 0,33 мкФ | 1 | Обвязка L7805 |
| 13 | Конденсатор керамический | 0,1 мкФ | 2 | Обвязка L7805 и LM393DT |
| 14 | Конденсатор керамический | 1 мкФ | 3 | Питание TLP152 |
| 15 | Конденсатор керамический | 10 мкФ | 1 | Питание NSM2012 |
| 16 | Конденсатор электролитический | 100 мкФ | 2 | Стабилизация питания L7805 и B0512S-2W |
| 17 | Конденсатор электролитический  (Low ESR) | 470 мкФ | 3 | Блок конденсаторов высоковольтного питания |
| 18 | Резистор | 100 Ом | 1 | Между D3 и UCC27517DBVR |
| 19 | Резистор | 220 Ом | 6 | Цепи управления оптодрайверами и оптопарой |
| 20 | Резистор | 20 Ом | 3 | Между TLP152 и мосфетами |
| 21 | Резистор | 10 кОм | 2 | Подтяжка к GND выхода компаратора и пина D7 Arduino |
| 22 | Резистор | 430 Ом – 1 кОм | 1 | Токоограничивающий для светодиода |
| 23 | Резистор нагрузочный (выносной) | 1,5 Ом, 100 Вт, тип AH-100 | 3 | Защита мосфетов при КЗ |
| 24 | Резистор подстроечный | 10 кОм | 1 | Настройка порога компаратора |
| 25 | Разъём | IN(12V), KF301-5.0-2P | 1 | Вход питания микроконтроллера |
| 26 | Разъём | IN(80V), KF301-5.0-2P | 1 | Вход высоковольтного питания |
| 27 | Разъём | ZX-XH2.54-3PZZ | 2 | Подключение потенциометров |
| 28 | Разъём | ZX-XH2.54-4PZZ | 1 | Выход HOLD/RESUME |
| 29 | Разъём | XH2.54-2PIN | 1 | Кнопка |
| 30 | Разъём | SH-XH2.54-2PWZ | 1 | Вход сигнала остановки |

---

## 📁 Как открыть файлы в EasyEDA

1. Откройте онлайн-редактор [EasyEDA](https://easyeda.com/editor) или запустите десктопное приложение.
2. В верхнем левом меню выберите: **Файл (File)** ➡️ **Открыть (Open)** ➡️ **EasyEDA...**
3. Загрузите интересующий вас `.json` файл.

---

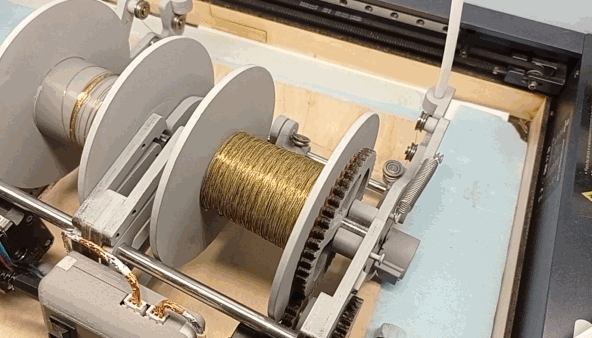
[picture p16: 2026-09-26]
~images/edm2.gif

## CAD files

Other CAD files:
CAD/Wire-supply/AS5600.ipt
CAD/Wire-supply/Nema-17.ipt
CAD/Wire-supply/Stepper 28BYJ-48.ipt
CAD/Wire-supply/U-подшипник.ipt
CAD/Wire-supply/Барабан катушки.ipt
CAD/Wire-supply/Бегунок.ipt
CAD/Wire-supply/Бесконечный винт.ipt
CAD/Wire-supply/Бортик внутренний (конусной катушки).ipt
CAD/Wire-supply/Бортик внутренний.ipt
CAD/Wire-supply/Бортик катушки.ipt
CAD/Wire-supply/Бортик конусной катушки.ipt
CAD/Wire-supply/Вал катушки (левой).ipt
CAD/Wire-supply/Вал катушки.ipt
CAD/Wire-supply/Вал шестерни (левой).ipt
CAD/Wire-supply/Вал шестерни.ipt
CAD/Wire-supply/Колпачок датчика.ipt
CAD/Wire-supply/Кольцо линейного подшипника.ipt
CAD/Wire-supply/Конусный барабан катушки.ipt
CAD/Wire-supply/Корпус платы.ipt
CAD/Wire-supply/Крепление линейного подшипника.ipt
CAD/Wire-supply/Крепление петли.ipt
CAD/Wire-supply/Крепление шкива.ipt
CAD/Wire-supply/Крышка корпуса платы.ipt
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

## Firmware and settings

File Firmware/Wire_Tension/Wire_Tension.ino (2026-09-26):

#include <TimerOne.h>
#include <GyverPID.h>

GyverPID regulator_1(150, 1, 0, 50); // объявляем PID регулятор

// Первый шаговый двигатель
#define STEP1_PIN 3
#define DIR1_PIN 2
#define ENABLE_1_PIN 6

// Второй шаговый двигатель
#define STEP2_PIN 5
#define DIR2_PIN 4
#define ENABLE_2_PIN 7

volatile unsigned long stepInterval1 = 0;
volatile unsigned long stepInterval2 = 0;
volatile bool stepState1 = LOW;
volatile bool stepState2 = LOW;
bool pick = 0;

int spd1 = 0, spd2 = 0;
unsigned long i = 0;

void setup() {
  pinMode(12, INPUT); // кнопка управления направлением вращения второго шаговика,  подаёт 5В во включённом состоянии, в выключенном через резистор 10кОм подтягивается к GND
  pinMode(ENABLE_1_PIN, OUTPUT); // пины enable драйверов шаговых двигателей (TMC2209)
  pinMode(ENABLE_2_PIN, OUTPUT);
  pinMode(8, OUTPUT);  // сигнальный светодиод (через резистор 220 Ом)
  pinMode(9, OUTPUT);  // от пина напрямую на пищалку подавать сигнал нельзя, так как слишком большой ток. Этот пин управляет драйвером UCC27517DBVR, который подаёт на пищалку 12В и выдерживает необходимый ток, от чего пищалка орёт как положено.

  pinMode(STEP1_PIN, OUTPUT); // пины драйверов шаговых двигателей
  pinMode(DIR1_PIN, OUTPUT);
  pinMode(STEP2_PIN, OUTPUT);
  pinMode(DIR2_PIN, OUTPUT);

  digitalWrite(STEP1_PIN, LOW);
  digitalWrite(STEP2_PIN, LOW);

  digitalWrite(ENABLE_1_PIN, LOW);
  digitalWrite(ENABLE_2_PIN, LOW);

  Timer1.initialize(10);
  Timer1.attachInterrupt(timerISR);

  setSpeed1(0);
  setSpeed2(0);

  PIDR();
}

void loop() {
  i++; // переменная i — костыль, который используется в качестве замены таймера, так как он сбит управлением шаговыми двигателями
  int ads = analogRead(A0);  // опрос пина OUT датчика AS5600 на рычаге, определяющим натяжение проволоки (AS5600 необходимо перевести в аналоговый режим)
  if ((ads < 15) || (ads > 500)) { // если вне рабочей зоны, значит рычаг в начальном положении (обрыв проволоки, либо стартовое положение и нужно вручную наклонить рычаг для запуска работы)
    setSpeed1(0); // останавливаем шаговые двигатели
    setSpeed2(0);
    digitalWrite(ENABLE_1_PIN, HIGH); // разблокируем шаговые двигатели
    digitalWrite(ENABLE_2_PIN, HIGH);
    alarm();  // запусаем пищалку и мигание светодиодом
  }
  else {
    digitalWrite(ENABLE_1_PIN, LOW); // активируем шаговые двигатели
    digitalWrite(ENABLE_2_PIN, LOW);

    regulator_1.input = ads; // расчёт скорости 1-го шагового двигателя с помощью PID регулятора исходя из положения рычага
    spd1 = regulator_1.getResult();
    setSpeed1(spd1);

    spd2 = map(analogRead(A1), 0, 1023, 0, 5000); // скорость второго шагового двигателя задаётся потенциометром на пине A1
    spd2 = constrain(spd2, 0, 5000);  // шаги в сек
    if (digitalRead(12)) setSpeed2(spd2);  // на пине D12 кнопка, подтягивающая 5В. Пин так же подтянут к земле через резистор 10кОм. Кнопка определяет направление вращения 2-го шагового двигателя 
    else setSpeed2(-spd2);

    if (i  > 40) {
      if (abs(spd2 - abs(spd1)) > 200) alarm_slippage();  // если скорости шаговых двигателей сильно различаются, значит проволока проскальзывает — издаём звуковой сигнал и мигаем светодиодом с интервалом, который задаётся костыльной переменной i
      i = 0;
    }
  }
}

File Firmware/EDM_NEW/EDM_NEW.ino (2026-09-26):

int q = 0;
uint16_t pulse_time = 2;
uint16_t pulse_delay = 1000;

void setup() {
  pinMode(A0, INPUT); // потенциометр на A0 (задаёт длительность импульса)
  pinMode(A1, INPUT); // потенциометр на A1 (задаёт паузу между импульсами)
  pinMode(7, INPUT);  // вход кнопки вкл/выкл регулировки частоты и длительности импульса → пин D7
  pinMode(4, INPUT);  // вход сигнала от компаратора датчика тока → пин D4
  pinMode(3, OUTPUT); // выход сигнала для управления мосфетом → пин D3
  pinMode(6, OUTPUT); // выход на оптопару STOP → пин D6
  pinMode(5, OUTPUT); // выход на оптопару RESUME → пин D5
}

void loop() {
  bool current_sensor = false;

  if (PIND & (1 << 7)) {  // если кнопка на пине D7 включена (подано 5В на пин D7), выключаем генерацию импульсов и запускаем опрос потенциометров
    digitalWrite(3, 0);   // закрываем мосфет
    digitalWrite(5, 0);   // выключаем оптопару RESUME
    digitalWrite(6, 1);   // включаем оптопару PAUSE (ставим станок на паузу)

    pulse_time = analogRead(A0);  // Чтение потенциометра на A0 (задаёт длительность импульса)
    pulse_delay = analogRead(A1); // Чтение потенциометра на A1 (задаёт паузу между импульсами)

    pulse_time = map(pulse_time, 0, 1024, 2, 25);  // ограничиваем длительность импульса в диапазон от 2 до 25 мкс
    pulse_time = constrain(pulse_time, 2, 25);  

    pulse_delay = map(pulse_delay, 0, 1024, 40, 1000);  // ограничиваем длительность паузы между импульсами в диапазон от 40 до 1000 мкс (задаёт частоту: 1-20 кГц)
    pulse_delay = constrain(pulse_delay, 40, 1000); 
  }

  else {           // если кнопка на пине D7 выключена (подано GND на пин D7), запускаем генерацию импульсов
    PORTD |= (1 << PD3);                 // подаём на пин D3 высокий сигнал (открываем транзистор)
    delayMicroseconds(pulse_time);       // выдерживаем длительность импульса
    current_sensor = (PIND & (1 << 4));  // читаем на пине D4 есть ли ток    
    PORTD &= ~(1 << PD3);                // подаём на пин D3 низкий сигнал (закрываем транзистор)
    delayMicroseconds(pulse_delay);      // пауза между импульсами

    if (current_sensor) { // если в момент импульса был ток, то добавляем к переменной "q" единицу
      q = q + 1;
      if (q > 1000) q = 1000;
    }
    else q = q - 1; // если в момент импульса не было тока, то отнимаем 1
    if (q < 0) q = 0;

    if (q <= 850) { // если полезных импульсов мало, жмём RESUME  (включаем оптопару на пине D5)
      digitalWrite(6, 0);
      digitalWrite(5, 1);
    }
    if (q >= 950) { // если полезных импульсов слишком много, жмём PAUSE (включаем оптопару на пине D6)
      digitalWrite(5, 0);
      digitalWrite(6, 1);
    }
  }
}

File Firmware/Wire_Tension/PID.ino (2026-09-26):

void PIDR(){  
  regulator_1.setDirection(NORMAL);
  regulator_1.setLimits(-8000, 8000); // скорость в шаг/сек
  regulator_1.setpoint = 130;           // значение analogRead() к которому стремится PID регулятор
  
  regulator_1.Kp = 100;
  regulator_1.Ki = 5;
  regulator_1.Kd = 0;  
}

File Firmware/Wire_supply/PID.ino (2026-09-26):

void PIDR(){  
  regulator_1.setDirection(REVERSE);
  regulator_1.setLimits(-18000, 18000); // скорость в шаг/сек
  regulator_1.setpoint = 150;           // значение analogRead() к которому стремится PID регулятор
  
  regulator_1.Kp = 150;
  regulator_1.Ki = 0.8;
  regulator_1.Kd = 0;
  
  regulator_2.setDirection(REVERSE);
  regulator_2.setLimits(-18000, 18000); // скорость в шаг/сек
  regulator_2.setpoint = 150;           // значение analogRead() к которому стремится PID регулятор
  
  regulator_2.Kp = 150;
  regulator_2.Ki = 0.8;
  regulator_2.Kd = 0;
  
}

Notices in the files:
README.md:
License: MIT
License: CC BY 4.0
